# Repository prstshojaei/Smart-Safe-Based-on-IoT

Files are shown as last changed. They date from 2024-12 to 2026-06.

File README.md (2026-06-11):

# Smart Safe Based on IoT

An IoT-enabled smart safe developed as my **BSc Electrical Engineering thesis** at Shahid Beheshti University. The system protects valuables through real-time monitoring, multi-layer authentication, and SMS alerts, built around an Arduino Uno with integrated sensors and GSM/GPS communication.

---

## Project Overview

The Smart Safe combines embedded programming, sensor integration, and SMS communication into a single security solution. Users can lock and unlock the safe through a two-step authentication process, receive alerts when tampering is detected, and track the safe's location remotely in case of theft.

## Key Features

- **Multi-layer authentication** — a password entered on the keypad, followed by a one-time ID sent to the user's phone via SMS, which must be entered to unlock the safe.
- **Vibration detection** — an SW-420 sensor detects physical tampering and triggers an SMS alert.
- **Motion detection** — a PIR sensor detects movement around the safe and sends an alert.
- **GPS location tracking** — a NEO-M8 module sends the safe's coordinates to the user every 10 minutes.
- **Remote control via SMS** — users can enable or disable sensors with commands such as `Motion_on` or `Vibr_on`.
- **Brute-force protection** — after three incorrect attempts, the safe locks for 15 minutes.
- **Persistent storage** — the password and phone number are stored in EEPROM so they survive power loss.

## Hardware Components

- **Arduino Uno** — main controller
- **SW-420** vibration sensor
- **PIR** motion sensor
- **NEO-M8** GPS module
- **SIM800L** GSM module (SMS)
- **16×2 LCD** display + **keypad** for the user interface
- **Relay lock**, buzzer, and a custom LM2596-based power module

## How It Works

The system runs several routines in parallel using timers:

- It checks for vibration and motion every few minutes and sends an SMS if either is triggered.
- It sends a GPS location update every 10 minutes.
- To unlock, the user enters a password, then an ID sent to their phone by SMS. Three failed attempts lock the safe for 15 minutes.

## Circuit & Build

### Schematic
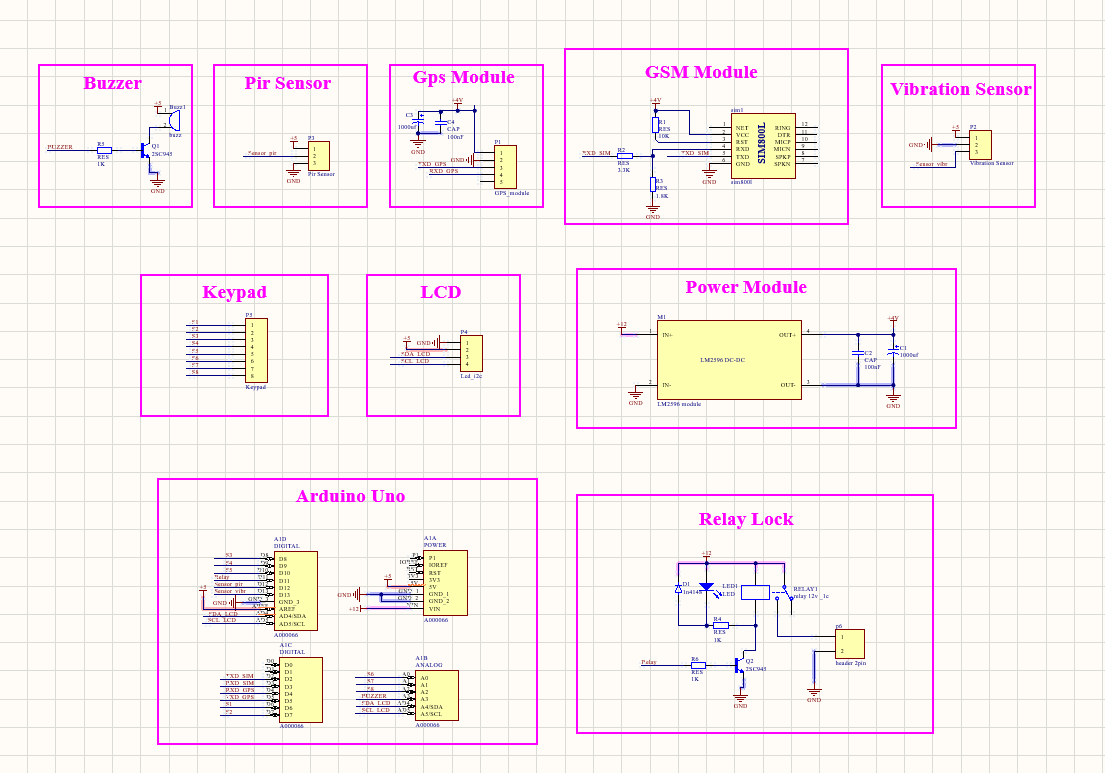
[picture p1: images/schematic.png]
Circuit schematic


### PCB (3D View)
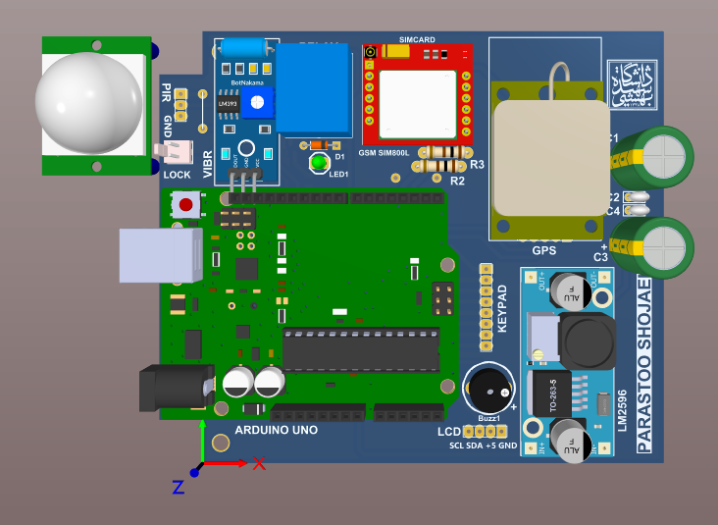
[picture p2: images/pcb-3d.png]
PCB 3D view


### Assembled Board
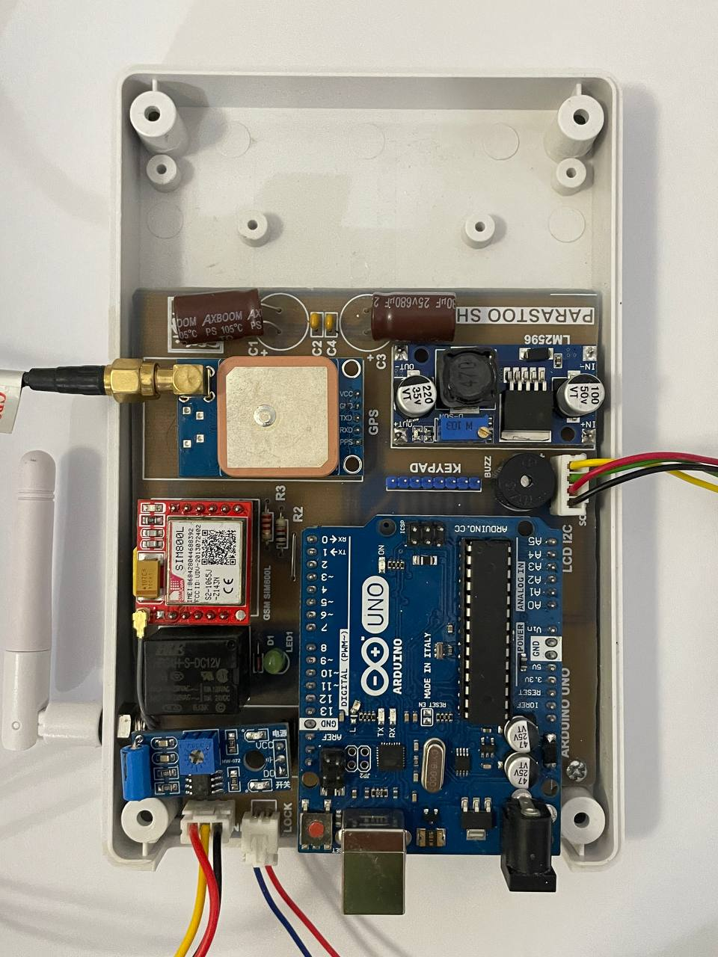
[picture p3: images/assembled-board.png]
Assembled board


### System Flowchart
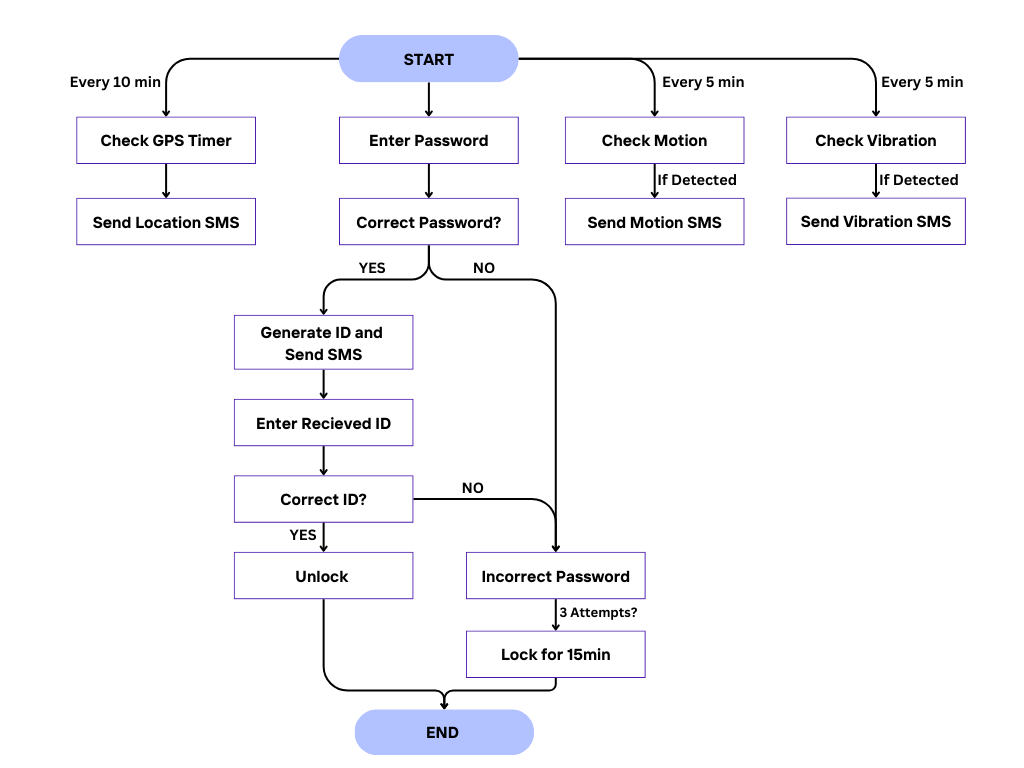
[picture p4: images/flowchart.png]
System flowchart


## Tech & Skills

Arduino · C++ · Embedded Systems · IoT · Sensor Integration · GSM/GPS · PCB Design · EEPROM

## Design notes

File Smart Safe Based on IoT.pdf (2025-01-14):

## Smart Safe Based on IoT

Project Overview

This project, developed as part of my Bachelor's thesis, involves the design and implementation of a Smart Safe system based on Internet of Things (IoT) technology. The goal was to create a secure, IoT-enabled safe that provides enhanced protection for valuable items through real-time monitoring, multi-layer authentication, and the ability to send notifications via SMS. The safe system integrates several sensors and communication modules, including a SW-420 vibration sensor, PIR motion sensor, NEO-M8 GPS module, and SIM800L GSM module for communication with the user. The project aimed to combine embedded systems programming, sensor integration, and SMS communication to build a reliable and effective security solution.

This smart safe system allows users to control and monitor their safe remotely, ensuring that their belongings are protected and that they are notified of any suspicious activity or tampering. The system also tracks the safe's location using GPS, providing real-time updates to the user in case of theft or unauthorized access.

Key Features and Functionality

1. Multi-Layer Authentication:
- The safe is secured with a password-based authentication system. After entering the correct password, the system prompts the user for an additional ID verification step via SMS, enhancing the security of the device.
- Password and OTP Verification: Users must enter a password and a randomly generated ID sent via SMS to unlock the safe, adding an extra layer of security to prevent unauthorized access.
2. Sensor Integration:
- Vibration Detection: The system uses the SW-420 vibration sensor to detect any physical tampering with the safe. When a vibration is detected, the system sends an alert to the user.
- Motion Detection: The PIR motion sensor detects movement around the safe, providing an additional layer of security. If motion is detected, the system triggers an alert.
3. Location Tracking:
- The NEO-M8 GPS module provides precise location tracking, sending real-time GPS coordinates to the user every 10 minutes, allowing them to track the safe’s location in case of theft.
4. SMS Communication:
- The SIM800L GSM module allows the system to send and receive SMS messages. When suspicious activity is detected (e.g., vibration or motion), the system sends an SMS alert to the user.

- The system also allows the user to remotely control features like vibration and motion sensors by sending specific SMS commands such as "Motion_on" or "Vibr_on."
5. User Interface:
- The user interface is displayed on a 16x2 LCD. It shows prompts for password entry, status updates, and alerts for the user. The keypad is used for password input and for entering commands.
- The LCD displays various system statuses, such as "Enter Password", "Enter ID", and "Unlock" based on the current step in the authentication process.
6. EEPROM Storage:
- The system stores the user's password and phone number in EEPROM memory to retain them even after the device is powered off. This ensures that the system can retrieve the stored data when required.
7. Security Features:
- If multiple incorrect attempts are made for either password or ID entry, the system locks for 15 minutes as a safety measure, preventing brute-force attacks.
- The buzzer emits a sound as an alert whenever there is an incorrect password attempt or other security events.

Technical Details and Hardware Components

The project relies heavily on Arduino as the main microcontroller, which manages the sensors, LCD, keypad, and communication modules. Below is a summary of the key hardware components used:

- Arduino Uno: The main controller that orchestrates all components, handles the logic for authentication, and interfaces with the sensors and modules.
- SW-420 Vibration Sensor: Detects vibrations that could indicate tampering with the safe.
- PIR Motion Sensor: Detects human motion around the safe for enhanced security.
- NEO-M8 GPS Module: Provides accurate location information of the safe using GNSS signals.
- SIM800L GSM Module: Facilitates communication via SMS, allowing the safe to send alerts and receive commands from the user.
- 16x2 LCD Display: Displays system prompts and information to the user.
- Keypad: Used by the user to enter the password and other commands.
- EEPROM: Stores the user’s password and phone number persistently.

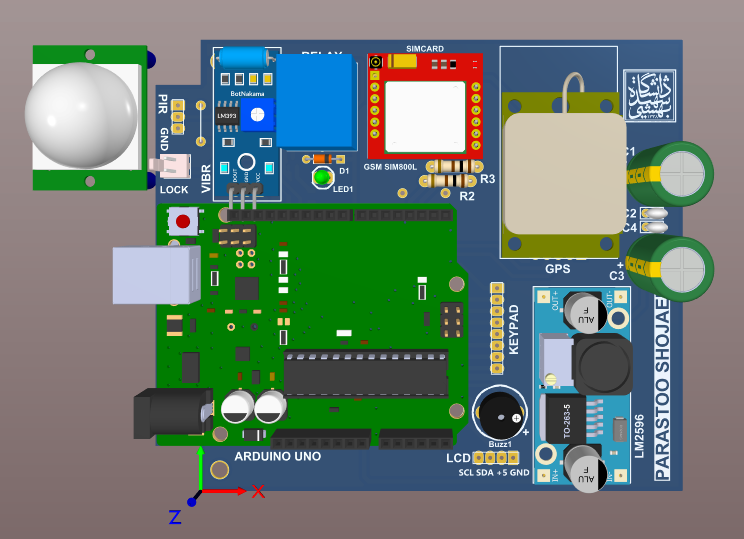
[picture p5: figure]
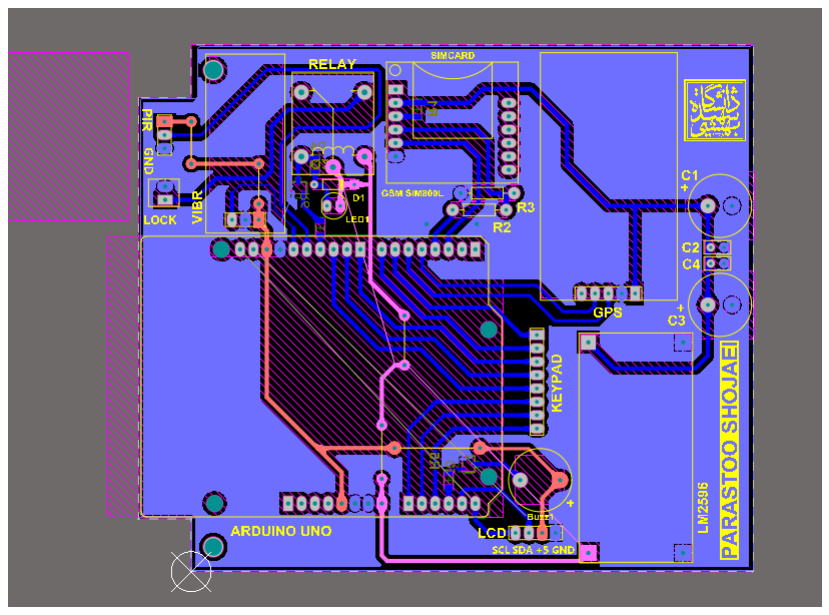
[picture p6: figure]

PCB layout designed for the Smart Safe system

Challenges and Solutions

1. Handling Multiple Sensors:
- Managing the multiple sensors (vibration, motion, and GPS) simultaneously was a challenge. This was overcome by using timers to handle each sensor's data collection and alerting in parallel, ensuring that the system remained responsive and efficient.

2. SMS Communication Reliability:
- One of the difficulties was ensuring reliable SMS communication through the SIM800L module. By carefully managing the timing of AT commands and checking the module’s response, I was able to ensure consistent performance.
3. GPS Accuracy:
- Initially, the GPS module provided some inaccurate readings. This was mitigated by ensuring that the GPS module had a clear view of the sky, and by implementing a check to only send location data once the GPS signal was valid.

Conclusion

The Smart Safe based on IoT project successfully integrates embedded systems, sensor technology, and SMS communication to create a secure, reliable, and user-friendly solution for protecting valuables. The project not only demonstrates the capabilities of Arduino and IoT systems but also highlights the importance of multi-layered security features in protecting sensitive items.

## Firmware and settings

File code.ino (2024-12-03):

#include <SoftwareSerial.h>
#include <TinyGPSPlus.h>
#include <Wire.h>
#include <LiquidCrystal_I2C.h>
#include <Keypad.h>
#include <EEPROM.h>
#include <stdio.h>
#include <stdlib.h>
#include <TimerOne.h>

static volatile int num = 0;

#define Password_Length 5
char Data[Password_Length];
char Number[14];
char password[5];
char Save_Number[14];
char Save_pass[5];
char* id;
char Master[Password_Length] = "123A";

const int sensorPin = 13;
unsigned long pulseCount = 0;
int lastSensorState = LOW;
int lockOutput = 11;
byte data_count = 0;
byte num_count = 0;
byte pass_count = 0;
byte step = 0, motion = 0, vibration = 0;
byte invalid_pass_count = 0;
int i = 0;
unsigned long t_vibration = 0;
unsigned long t_motion = 0;
unsigned long t_location = 0;
unsigned long t_unlock = 0;
unsigned long startMillis = 0;
bool timerStarted = false;
const unsigned long interval = 120000;
int count_location = 0;
char location[100];
String buffer_text;

char customKey;

const byte ROWS = 4;
const byte COLS = 4;

char hexaKeys[ROWS][COLS] = {
    {'1', '2', '3', 'A'},
    {'4', '5', '6', 'B'},
    {'7', '8', '9', 'C'},
    {'*', '0', '#', 'D'}
};

byte rowPins[ROWS] = {6, 7, 8, 9};
byte colPins[COLS] = {10, A0, A1, A2};

Keypad customKeypad = Keypad(makeKeymap(hexaKeys), rowPins, colPins, ROWS, COLS);

SoftwareSerial Sim_serial(2, 3);
SoftwareSerial Gps_serial(5, 4);

TinyGPSPlus gps;

#define TIME_OUT 5000
#define Pir_sensor 12
#define Rst_Sim800 1
#define buzzer A3
LiquidCrystal_I2C lcd(0x27, 16, 2);

void setup() {
    Serial.begin(9600);
    Sim_serial.begin(9600);
    lcd.init();
    lcd.clear();
    lcd.backlight();

    pinMode(sensorPin, INPUT);
    pinMode(lockOutput, OUTPUT);
    digitalWrite(lockOutput, LOW);
    pinMode(Pir_sensor, INPUT);
    pinMode(buzzer, OUTPUT);
    pinMode(Rst_Sim800, OUTPUT);
    digitalWrite(Rst_Sim800, LOW);
    lcd.setCursor(0, 0);
    lcd.print("Loading...");

    while (i < 4000) {
        i++;
        lcd.setCursor(0, 1);
        lcd.print(i / 40);
        lcd.print("%");
        delay(1);
    }

    send_command("ATE0");
    send_command("AT+CSMP=49,167,0,0");
    send_command("AT+CNMI=2,2,0,0,0");
    send_command("AT+CMGF=1");
    delet_sms();
    EEPROM.get(0, Save_Number);
    delay(100);
    EEPROM.get(20, Save_pass);
    chek_number(Save_Number);
    chek_password(Save_pass);
    motion = EEPROM.read(200);
    vibration = EEPROM.read(201);
    if (!chek_number(Save_Number) | !chek_password(Save_pass))
        step = 2;

    lcd.clear();
    lcd.setCursor(0, 0);
    chek_location();
    send_sms(Number, location);
    Timer1.initialize(1000);
    Timer1.attachInterrupt(checkPulse);
}

void loop() {
    unsigned long currentMillis = millis();

    chek_sms();

    if (pulseCount > 10 && currentMillis - t_vibration >= 300000) {
        send_sms(Number, "Vibration Detect");
        Serial.print("Pulse ");
        Serial.println(pulseCount);
        pulseCount = 0;
        t_vibration = millis();
    }

    if (digitalRead(Pir_sensor) == HIGH && motion == 1 && currentMillis - t_motion >= 300000) {
        send_sms(Number, "Motion Detect");
        Serial.println("send sms pir");
        t_motion = millis();
    }
    if (currentMillis - t_location >= 600000) {
        t_location = millis();
        chek_location();
        send_sms(Number, location);
    }

    lcd.setCursor(0, 0);
    if (step == 0)
        lcd.print("Enter Password:");
    else if (step == 1)
        lcd.print("Enter Id SMS  :");
    else if (step == 2)
        lcd.print("UNLOCK");
    else if (step == 3)
        lcd.print("Enter Number :");

    customKey = customKeypad.getKey();
    if (customKey) {
        beeb();
        if (step < 2) {
            Data[data_count] = customKey;
            lcd.setCursor(data_count, 1);
            lcd.print(Data[data_count]);
            data_count++;
        } else if (step == 2) {
            if (customKey == '*') step = 0;
            if (customKey == 'A') {
                step = 3;
                num_count = 0;
                lcd.setCursor(0, 0);
                lcd.print("Enter Number :");
                lcd.setCursor(0, 1);
                lcd.print(Number);
            }
            if (customKey == 'B') {
                step = 4;
                pass_count = 0;
                lcd.setCursor(0, 0);
                lcd.print("Enter New Pass:");
                lcd.setCursor(0, 1);
                lcd.print(password);
            }
        } else if (step == 3) {
            if (customKey != 'A' && customKey != 'B' && customKey != 'C' && customKey != 'D' && customKey != '*' && customKey != '#') {
                lcd.clear();
                lcd.setCursor(0, 0);
                lcd.print("Enter Number :");
                if (num_count > 11) {
                    lcd.clear();
                    clearNumber();
                }
                Number[num_count] = customKey;
                Number[num_count + 1] = '\0';
                lcd.setCursor(0, 1);
                lcd.print(Number);
                num_count++;
            } else if (customKey == '*') {
                lcd.clear();
                step = 2;
                num_count = 0;
            } else if (customKey == '#') {
                lcd.clear();
                if (num_count == 12) {
                    lcd.print("Save Number");
                    EEPROM.put(0, Number);
                } else {
                    lcd.print("NO Save Number");
                    EEPROM.get(0, Number);
                }
                delay(3000);
                step = 2;
                lcd.clear();
            }
        } else if (step == 4) {
            lcd.clear();
            lcd.setCursor(0, 0);
            lcd.print("Enter New Pass:");
            if (customKey != '*' && customKey != '#') {
                if (pass_count > 3) {
                    pass_count = 0;
                    password[0] = password[1] = password[2] = password[3] = 0;
                    password[4] = 0;
                }
                password[pass_count] = customKey;
                password[pass_count + 1] = '\0';
                pass_count++;
                lcd.setCursor(0, 1);
                lcd.print(password);
            } else if (customKey == '*') {
                lcd.clear();
                step = 2;
                pass_count = 0;
            } else if (customKey == '#') {
                lcd.clear();
                if (pass_count == 4) {
                    lcd.print("Save Password");
                    EEPROM.put(20, password);
                } else {
                    lcd.print("NO Save Pass");
                    EEPROM.get(20, password);
                }
                delay(3000);
                step = 2;
                lcd.clear();
            }
        }
    }

    if (data_count == Password_Length - 1) {
        lcd.clear();
        if (step == 0) {
            if (!strcmp(Data, password)) {
                lcd.print("Correct Pass");
                step = 1;
                invalid_pass_count = 0;
                id = random_num(4);
                send_sms(Number, id);
            } else {
                invalid_pass_count++;
                Alarm();
                if (invalid_pass_count > 2) {
                    lcd.print("LOCK FOR 15 MINE");
                    send_sms(Number, "LOCK FOR 15 MINE");
                    wait(900000);
                } else {
                    lcd.print("Incorrect");
                    send_sms(Number, "Incorrect Password");
                    delay(1000);
                }
            }
        } else if (step == 1) {
            if (!strcmp(Data, id)) {
                lcd.print("Correct id");
                digitalWrite(lockOutput, HIGH);
                delay(3000);
                digitalWrite(lockOutput, LOW);
                step = 2;
                send_sms(Number, "Unlock");
                invalid_pass_count = 0;
            } else {
                invalid_pass_count++;
                Alarm();
                if (invalid_pass_count > 2) {
                    lcd.print("LOCK FOR 15 MINE");
                    send_sms(Number, "LOCK FOR 15 MINE");
                    wait(900000);
                } else {
                    lcd.print("Incorrect id");
                    id = random_num(4);
                    send_sms(Number, id);
                    delay(1000);
                }
            }
        }
        lcd.clear();
        clearData();
    }
}

void checkPulse() {
    static int lastState = LOW;
    int currentState = digitalRead(sensorPin);

    if (currentState != lastState && vibration == 1) {
        pulseCount++;
        lastState = currentState;
        Serial.print("Pulse ");
        Serial.println(pulseCount);
    }
}

void Alarm() {
    digitalWrite(buzzer, HIGH);
    delay(1000);
    digitalWrite(buzzer, LOW);
    delay(100);
}

void beeb() {
    digitalWrite(buzzer, HIGH);
    delay(50);
    digitalWrite(buzzer, LOW);
    delay(50);
}

void clearData() {
    while (data_count != 0) {
        Data[data_count--] = 0;
    }
    return;
}

void clearNumber() {
    while (num_count != 0) {
        Number[num_count--] = 0;
    }
    return;
}

char* random_num(int num) {
    static char id[16];
    const char digits[] = "0123456789ABCD";
    id[0] = '\0';
    srand(millis());
    for (int i = 0; i < num; ++i) {
        id[i] = digits[rand() % 14];
    }
    id[num] = '\0';
    return id;
}

void chek_location() {
    int t = 0;
    char str_a[20];
    char str_b[20];
    double a = 0, b = 0;
    Gps_serial.begin(9600);
    while (t < 1000) {
        while (Gps_serial.available() > 0) {
            if (gps.encode(Gps_serial.read())) {
                if (gps.location.isValid()) {
                    a = gps.location.lat();
                    b = gps.location.lng();
                    dtostrf(a, 10, 6, str_a);
                    dtostrf(b, 10, 6, str_b);
                    sprintf(location, "%s,%s ", str_a, str_b);
                } else {
                    sprintf(location, "%s ", "INVALID");
                }
            }
        }
        delay(1);
        t++;
    }
    Serial.println(location);
    Sim_serial.begin(9600);
}

void delet_sms() {
    Sim_serial.println("AT+CMGDA=\"DEL ALL\"");
    delay(10000);
}

bool send_sms(char* number, String msg) {
    Sim_serial.begin(9600);
    delay(1000);
    Sim_serial.println("AT+CMGF=1");
    delay(1000);
    Sim_serial.print("AT+CMGS=\"");
    Sim_serial.print(number);
    Sim_serial.println("\"");
    delay(1000);
    Sim_serial.println(msg);
    delay(1000);
    Sim_serial.print(char(26));
    return 0;
}

void chek_sms() {
    String buffer = read_command(1000);

    if (buffer.length() > 0) {
        if (buffer.indexOf("Motion_on") != -1) {
            Serial.println("Motion ON");
            send_sms(Number, "Motion ON");
            EEPROM.write(200, 1);
            motion = 1;
        } else if (buffer.indexOf("Motion_off") != -1) {
            Serial.println("Motion OFF");
            send_sms(Number, "Motion OFF");
            EEPROM.write(200, 0);
            motion = 0;
        } else if (buffer.indexOf("Location") != -1) {
            Serial.println("Loaction search");
            chek_location();
            send_sms(Number, location);
        } else if (buffer.indexOf("Vibr_on") != -1) {
            Serial.println("vibration ON");
            send_sms(Number, "Vibration ON");
            EEPROM.write(201, 1);
            vibration = 1;
        } else if (buffer.indexOf("Vibr_off") != -1) {
            Serial.println("vibration OFF");
            send_sms(Number, "Vibration OFF");
            EEPROM.write(201, 0);
            vibration = 0;
        }
        Serial.println(buffer);
    }
}

void wait(uint32_t timewait) {
    uint64_t timeOld = millis();
    while (!(millis() > timeOld + timewait));
}

bool chek_number(char* num) {
    const char digits[] = "0123456789";
    int len = strlen(num);
    int ok = 0;

    if (len >= 12) {
        for (int j = 0; j < 12; j++) {
            ok = 0;
            for (int n = 0; n < 10; n++) {
                if (num[j] == digits[n]) {
                    Number[j] = num[j];
                    ok = 1;
                    break;
                }
            }
            if (ok == 0) return 0;
        }
        Number[12] = '\0';
    }

    len = strlen(Number);
    if (len != 12) return 0;

    return 1;
}

bool chek_password(char* num) {
    const char digits[] = "0123456789ABCD";
    int len = strlen(num);
    int ok = 0;

    if (len >= 4) {
        for (int j = 0; j < 4; j++) {
            ok = 0;
            for (int n = 0; n < 14; n++) {
                if (num[j] == digits[n]) {
                    password[j] = num[j];
                    ok = 1;
                    break;
                }
            }
            if (ok == 0) return 0;
        }
        password[4] = '\0';
    }

    len = strlen(password);
    if (len != 4) return 0;

    return 1;
}

void send_command(String cmd) {
    Sim_serial.println(cmd);
    Serial.println(cmd);
    delay(2000);
}

void read_sensor() {
    int currentSensorState = digitalRead(sensorPin);

    if (currentSensorState != lastSensorState) {
        pulseCount++;
        lastSensorState = currentSensorState;
    }
}

String read_command(uint16_t timeout) {
    String str = "";

    if (Sim_serial.available()) {
        while (Sim_serial.available()) {
            char c = Sim_serial.read();
            str += c;
        }
    }

    return str;
}
